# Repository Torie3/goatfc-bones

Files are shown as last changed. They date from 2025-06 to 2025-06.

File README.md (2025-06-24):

# 🐐 GoatFC-Bones - Open Source FPV Flight Controller

<div align="left">
  <p>
    <strong>GoatFC-Bones</strong> is a compact, cheap, open-source FPV drone flight controller designed for racing builds without sacrificing performance. It’s ideal for hobbyists who want simple hardware so that they can easily understand what is happening in their quadcopter.
  </p>
</div>

GoatFC-Bones Flight Controller

## 🔧 Key Features

- **Voltage Regulation:**
  - 5V and 12V BEC outputs
  - Dual 3.3V LDOs:
    - One dedicated to the IMU for **noise isolation**
    - One for the rest of the system

- **Connectivity:**
  - Micro-USB for configuration
  - 20x20mm standard mounting pattern
  - ESC connector for clean wiring
  - 6-pin HD video system plug

- **Software:**
  - Compatible with [Betaflight](https://betaflight.com/) no official target yet!

- **License & Use:**
  - **Open-source** – build it, modify it, improve it
  - **Non-commercial** – redistribution for sale is **not allowed**
## 🧷 Pinout Diagram

Below is the pinout for the GoatFC-Bones flight controller. Make sure to reference this schematic when wiring your components.

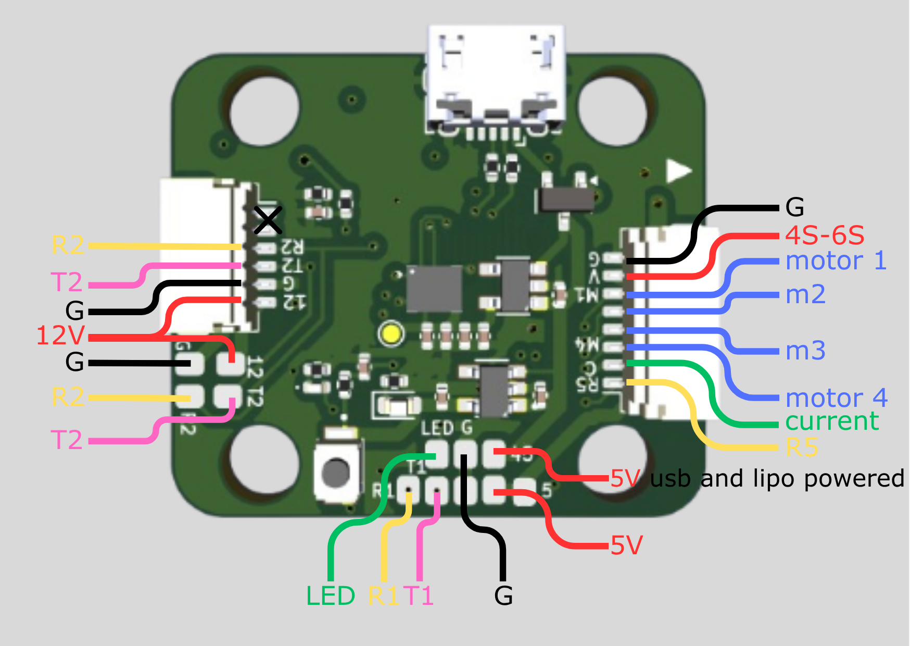
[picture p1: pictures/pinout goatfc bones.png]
GoatFC-Bones Pinout


> ⚠️ **Note:** The dedicated 3.3V regulators *are* broken out on the board, but **they are not intended for external use**. If you're curious about their exact location or implementation, please refer to the KiCad design files. Avoid connecting anything to these lines unless you fully understand the design — using them improperly may cause instability or damage.

> 🔌 Always double-check with a multimeter before connecting components!
## 🛠️ Building Your Own GoatFC-Bones

Amazing that you want to build one!

You can order the PCBs from your favorite PCB manufacturer — the Gerber files are available in the folder:  
[Gerber Files Folder](./gerber%20files)

### 📦 Bill of Materials (BOM)

The BOM is provided as an **interactive BOM**, which you can view here:  
[Download and open html file here](./interactive-bom)

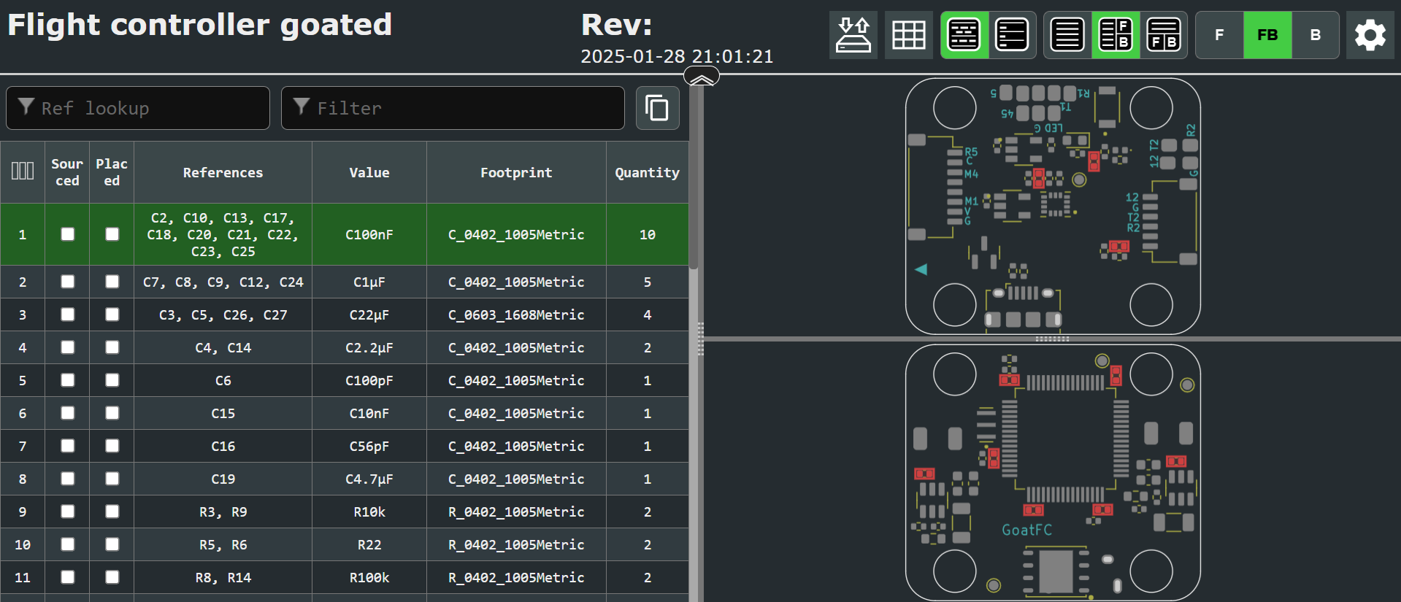
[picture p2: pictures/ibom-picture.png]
IBOM showcase


The iBOM makes it easy to locate and identify all the required components. Just search for the parts and order them from your preferred distributor.

### 🔧 Assembly Tips

- Solder all components following the iBOM placement guide
- Use **solder paste** and a **hot air station** for best results
- All components are **0402 size** — small, but manageable with some patience
- If you're new to SMD soldering, it's a good idea to practice on a scrap board first!

Good luck, and enjoy flying with your custom GoatFC-Bones FC!

## Flashing Betaflight to GoatFC-Bones

Follow these steps to flash Betaflight firmware to your GoatFC-Bones flight controller:

### Requirements
- A fully assembled GoatFC-Bones FC
- [Betaflight Configurator](https://github.com/betaflight/betaflight-configurator/releases) (latest version) installed on your PC

### Flashing Steps

1. **Build and assemble** your GoatFC-Bones FC.
2. **Install the latest Betaflight Configurator** on your computer.
3. **Enter DFU mode**:
   - Hold down the **boot button** on the FC while plugging in the **Micro-USB** cable.
4. In Betaflight Configurator, your FC should now show up as **DFU Bootloader**.
5. Go to the **Firmware Flasher** tab.
6. Under **Board**, select:  
   **`FOXEERF722V4`** (GoatFC-Bones shares a pinout with the Foxeer Mini V4).
7. Choose your preferred **firmware version** from the dropdown.
8. Click **Load Firmware [Online]**.
9. Then click **Flash Firmware**.
10. Once flashing is complete, the firmware is installed and ready to go! 🎉

### ⚠️ Important: Motor Remapping Required

Because the motor layout on GoatFC-Bones differs from the Foxeer Mini V4, you must **remap the motors** in the CLI:

1. Go to the **CLI** tab
2. In the cli type:
```
resource MOTOR 1 PC08
resource MOTOR 2 PC09
resource MOTOR 3 PA08
resource MOTOR 4 PA09
save
```
4. Now your motors should be in the correct order.
- You only need to do this once — after that, you can **save your configuration as a preset** to reload easily next time.

> 💡 Tip: After remapping, test motor directions in the “Motors” tab and double-check the order before your first flight.

---

## ⚠️ Disclaimer

This project is provided **as-is** without any warranty or guarantee of functionality or safety.

By using the GoatFC-Bones design files, firmware configurations, or build instructions, you acknowledge and agree that:

- You are solely responsible for your own safety and the safety of others.
- You assume all risks associated with the assembly, flashing, and use of this hardware.
- I (the creator) am **not liable** for any damage, injury, loss, or malfunction resulting from the use, misuse, or failure of this project.
- Always follow proper electrical and flight safety practices, and ensure compliance with your local laws and regulations.

> 🚧 Use at your own risk. This is an open-source DIY project intended for educational and recreational purposes (drone racing an amazing hobby!).

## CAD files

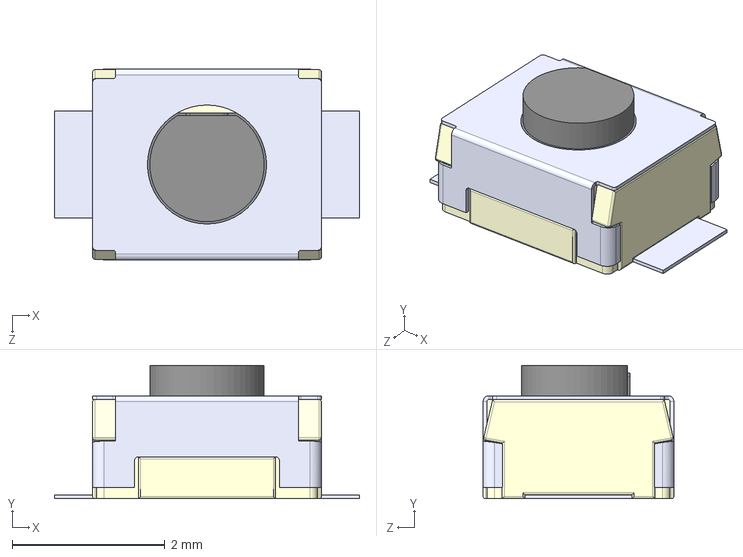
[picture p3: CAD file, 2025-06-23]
custom symbols and footprints/button/boot button/B3U-1000P/B3U-1000P.step
4.00 x 1.75 x 2.50 mm

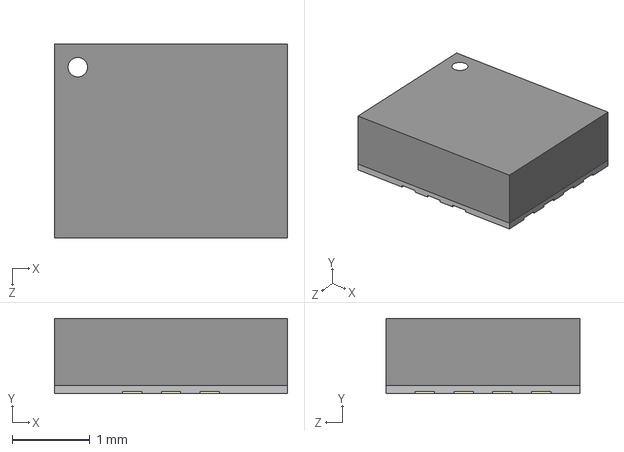
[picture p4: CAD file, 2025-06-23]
custom symbols and footprints/Chips/gyro/ICM-42688-P/ICM-42688-P.step
3.00 x 0.97 x 2.50 mm

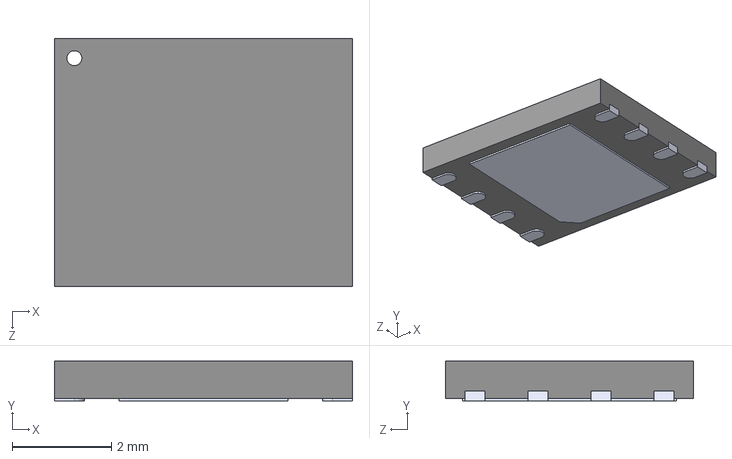
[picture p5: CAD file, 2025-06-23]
custom symbols and footprints/Chips/memory/W25Q128JVPIQ/W25Q128JVPIQ.step
6.00 x 0.8 x 5.00 mm

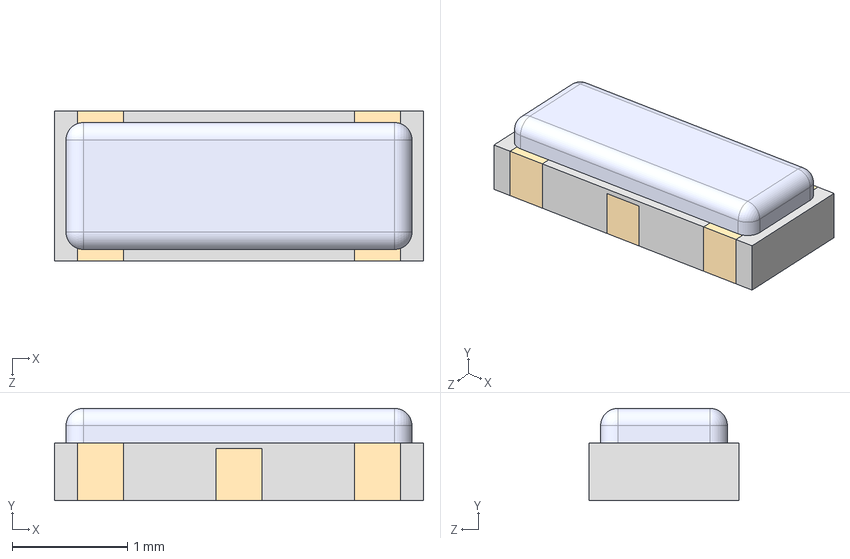
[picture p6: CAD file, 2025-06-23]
custom symbols and footprints/Chips/oscillator/CSTNE8M00G550000R0/CSTNE8M00G550000R0.step
3.20 x 0.8 x 1.30 mm

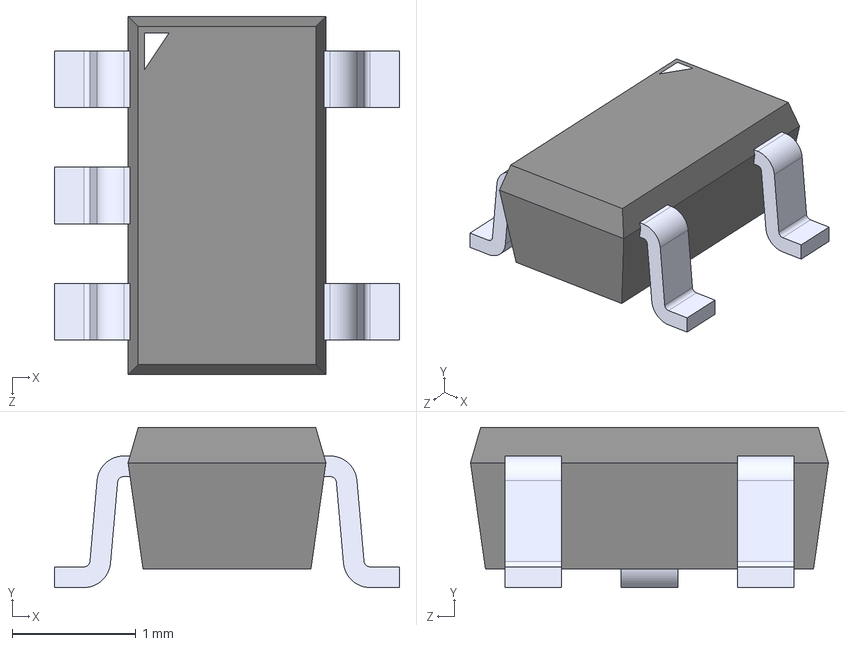
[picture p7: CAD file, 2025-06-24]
custom symbols and footprints/Chips/voltage regulator/RT9013-33GB/RT9013-33GB.step
2.79 x 1.30 x 2.90 mm

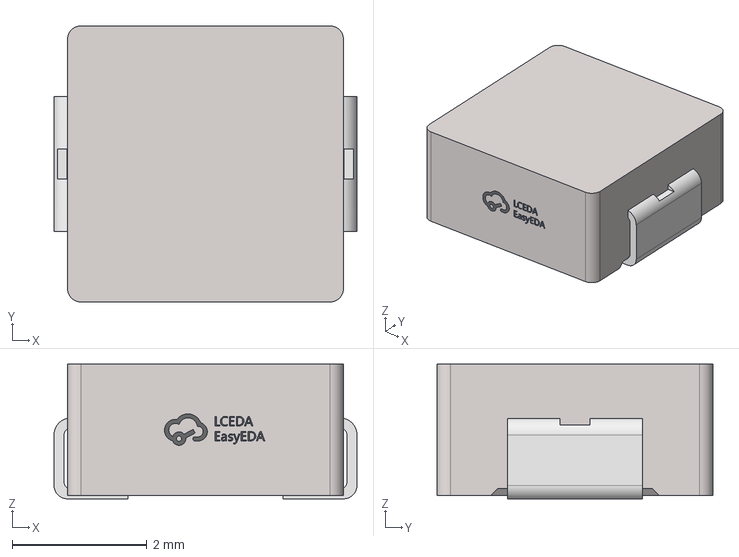
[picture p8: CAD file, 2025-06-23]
custom symbols and footprints/coils/TECHFUSE SL0420-100M.stp
4.50 x 4.10 x 2.00 mm

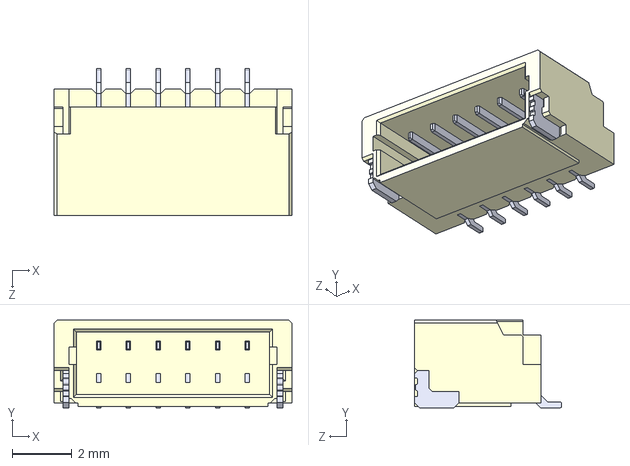
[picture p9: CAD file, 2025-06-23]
custom symbols and footprints/Connectors/jst-sh1.0/SM06B-SRSS-TB_LF__SN_/SM06B-SRSS-TB_LF__SN_.step
8.00 x 2.95 x 4.95 mm

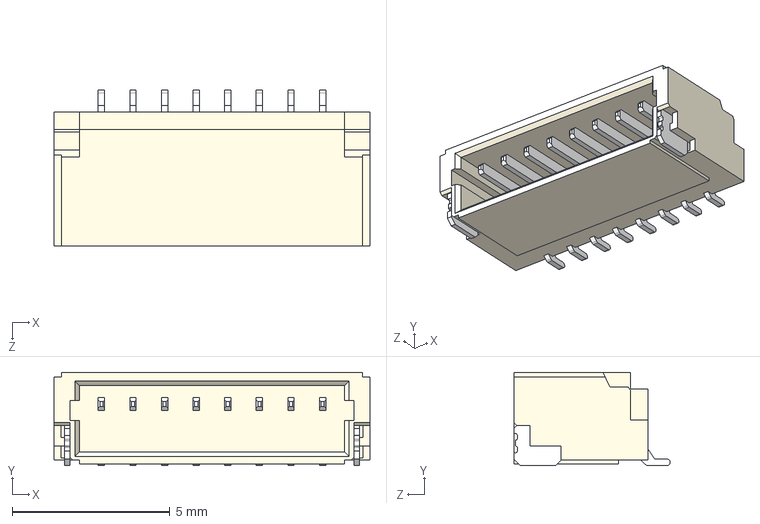
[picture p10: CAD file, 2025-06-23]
custom symbols and footprints/Connectors/jst-sh1.0/SM08B-SRSS-TB_LF__SN_/SM08B-SRSS-TB_LF__SN_.step
10.00 x 2.95 x 4.95 mm

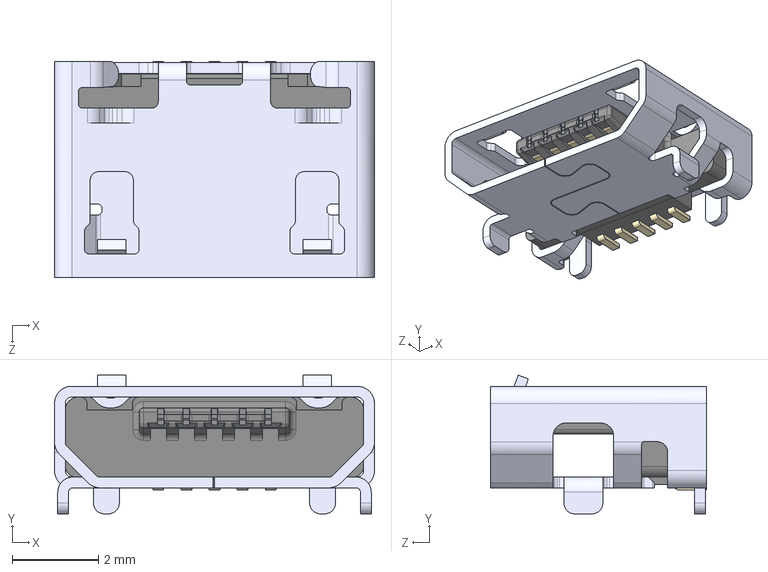
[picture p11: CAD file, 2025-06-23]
custom symbols and footprints/Connectors/usb/10118194-0011LF/10118194-0011LF.step
7.40 x 3.21 x 5.00 mm

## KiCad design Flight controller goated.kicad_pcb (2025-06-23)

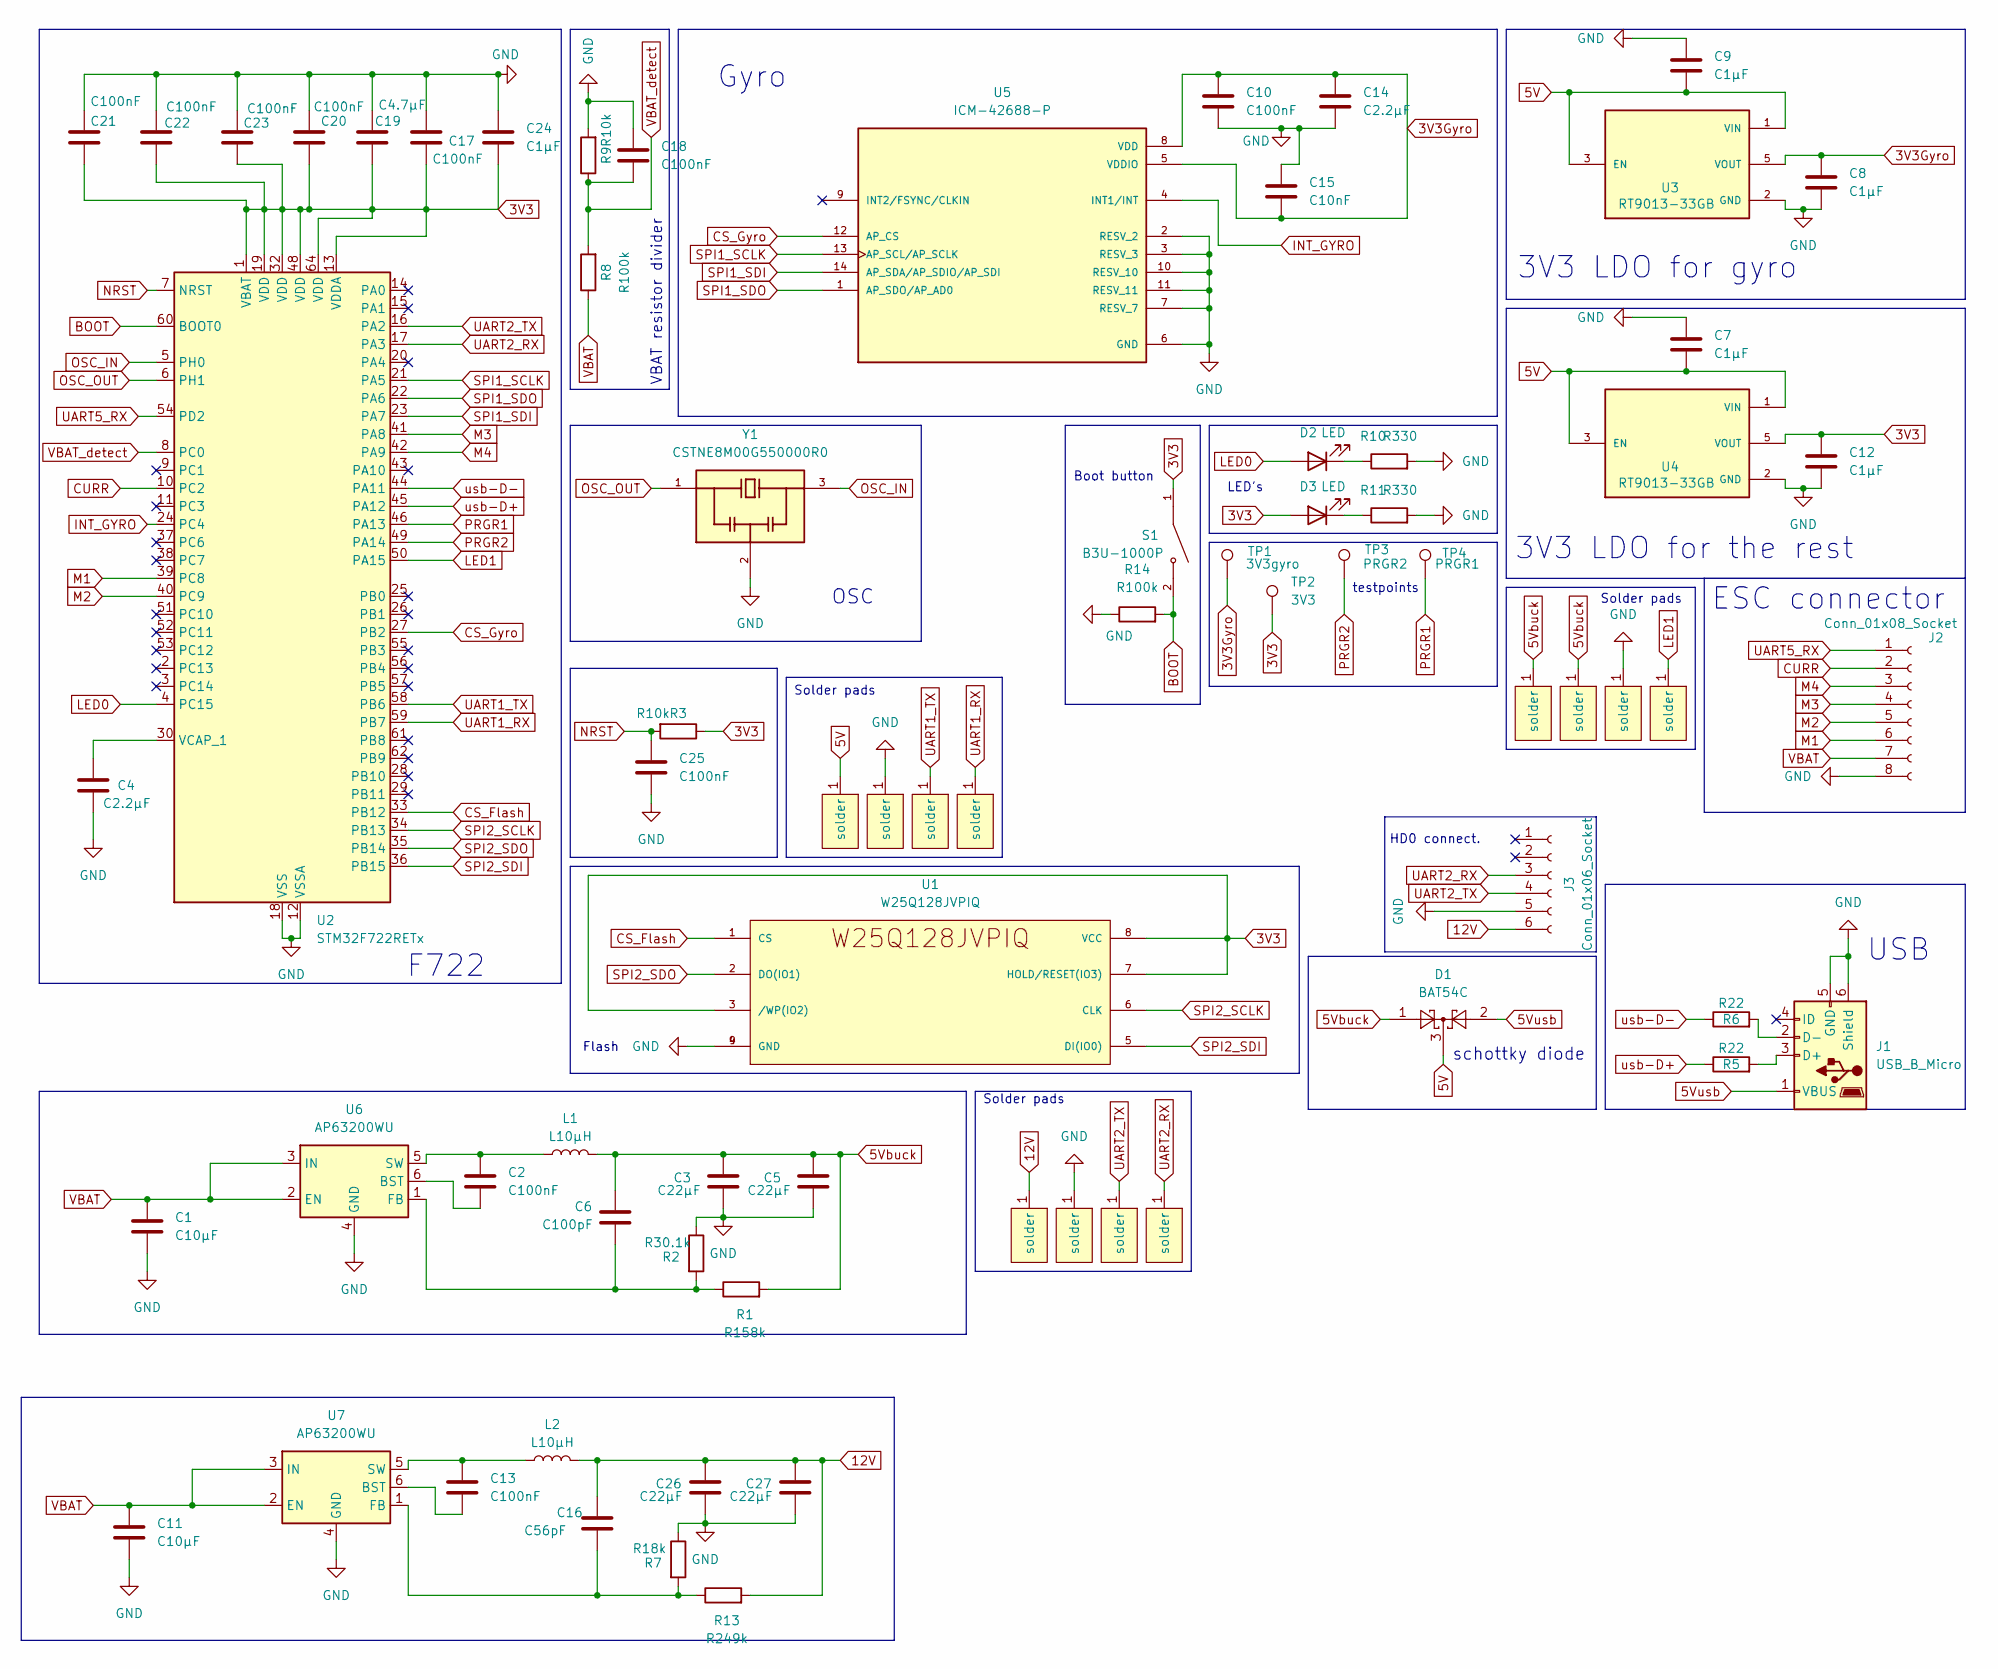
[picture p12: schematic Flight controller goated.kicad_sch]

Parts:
C1, C11: C10µF; C_1206_3216Metric
C2, C10, C13, C17, C18, C20, C21, C22, C23, C25: C100nF; C_0402_1005Metric
C3, C5, C26, C27: C22µF; C_0603_1608Metric
C4, C14: C2.2µF; C_0402_1005Metric
C6: C100pF; C_0402_1005Metric
C7, C8, C9, C12, C24: C1µF; C_0402_1005Metric
C15: C10nF; C_0402_1005Metric
C16: C56pF; C_0402_1005Metric
C19: C4.7µF; C_0402_1005Metric
D1: BAT54C; SOT-23
D2: LED; LED_0402_1005Metric
D3: LED; LED_0603_1608Metric
J1: USB_B_Micro; USB_Micro-B_Amphenol_10118194-0001LF_Horizontal
J2: Conn_01x08_Socket; JST_SH_SM08B-SRSS-TB_1x08-1MP_P1.00mm_Horizontal
J3: Conn_01x06_Socket; JST_SH_SM06B-SRSS-TB_1x06-1MP_P1.00mm_Horizontal
L1, L2: L10µH; TECHFUSE SL0420-100M
R1: R158k; R_0603_1608Metric
R2: R30.1k; R_0402_1005Metric
R3, R9: R10k; R_0402_1005Metric
R5, R6: R22; R_0402_1005Metric
R7: R18k; R_0402_1005Metric
R8, R14: R100k; R_0402_1005Metric
R10, R11: R330; R_0402_1005Metric
R13: R249k; R_0603_1608Metric
S1: B3U-1000P; SW_B3U-1000P
S2, S3, S4, S5, S6, S7, S8, S9, S10, S11, S12, S13: solder pad; solder pad small
TP1: 3V3gyro; TestPoint_Pad_D1.0mm
TP2: 3V3; TestPoint_Pad_D1.0mm
TP3: PRGR2; TestPoint_Pad_D1.0mm
TP4: PRGR1; TestPoint_Pad_D1.0mm
U1: W25Q128JVPIQ
U2: STM32F722RETx; LQFP-64_10x10mm_P0.5mm
U3, U4: RT9013-33GB; SOT94P279X129-5N; PARTREV Aprill 2011
U5: ICM-42688-P; PQFN50P300X250X97-14N; PARTREV 1.2
U6, U7: AP63200WU; TSOT-23-6
Y1: CSTNE8M00G550000R0; OSC_CSTNE8M00G550000R0

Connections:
3V3: C12.1, C17.2, C19.2, C20.2, C21.2, C22.2, C23.2, C24.2, D3.2 (A), R3.1, S1.1, TP2.1, U1.3 (/WP(IO2)), U1.7 (HOLD/RESET(IO3)), U1.8 (VCC), U2.1 (VBAT), U2.13 (VDDA), U2.19 (VDD), U2.32 (VDD), U2.48 (VDD), U2.64 (VDD), U4.5 (VOUT)
3V3Gyro: C8.1, C10.1, C14.1, C15.2, TP1.1, U3.5 (VOUT), U5.5 (VDDIO), U5.8 (VDD)
5V: C7.2, C9.2, D1.3, S6.1 (solder), U3.1 (VIN), U3.3 (EN), U4.1 (VIN), U4.3 (EN)
5Vbuck: C3.1, C5.1, C6.2, D1.1, L1.2, R1.2, S10.1 (solder), S13.1 (solder)
5Vusb: D1.2, J1.1 (VBUS)
12V: C16.2, C26.1, C27.1, J3.6, L2.2, R13.2, S2.1 (solder)
BOOT: R14.2, S1.2, U2.60 (BOOT0)
CS_Flash: U1.1 (CS), U2.33 (PB12)
CS_Gyro: U2.27 (PB2), U5.12 (AP_CS)
CURR: J2.2, U2.10 (PC2)
GND: C1.2, C3.2, C4.2, C5.2, C7.1, C8.2, C9.1, C10.2, C11.2, C12.2, C14.2, C15.1, C17.1, C18.1, C19.1, C20.1, C21.1, C22.1, C23.1, C24.1, C25.2, C26.2, C27.2, J1.5 (GND), J1.6 (Shield), J2.8, J3.5, R2.1, R7.1, R9.2, R10.2, R11.2, R14.1, S3.1 (solder), S7.1 (solder), S11.1 (solder), U1.4 (GND), U1.9 (GND), U2.12 (VSSA), U2.18 (VSS), U2.31 (VSS), U2.47 (VSS), U2.63 (VSS), U3.2 (GND), U4.2 (GND), U5.2 (RESV_2), U5.3 (RESV_3), U5.6 (GND), U5.7 (RESV_7), U5.10 (RESV_10), U5.11 (RESV_11), U6.4 (GND), U7.4 (GND), Y1.2
INT_GYRO: U2.24 (PC4), U5.4 (INT1/INT)
LED0: D2.2 (A), U2.4 (PC15)
LED1: S12.1 (solder), U2.50 (PA15)
M1: J2.6, U2.39 (PC8)
M2: J2.5, U2.40 (PC9)
M3: J2.4, U2.41 (PA8)
M4: J2.3, U2.42 (PA9)
NRST: C25.1, R3.2, U2.7 (NRST)
unnamed: D2.1 (K), R10.1
unnamed: D3.1 (K), R11.1
unnamed: J1.3 (D+), R5.2
unnamed: J1.2 (D-), R6.2
unnamed: C4.1, U2.30 (VCAP_1)
unnamed: C2.2, U6.6 (BST)
unnamed: C6.1, R1.1, R2.2, U6.1 (FB)
unnamed: C2.1, L1.1, U6.5 (SW)
unnamed: C13.2, U7.6 (BST)
unnamed: C16.1, R7.2, R13.1, U7.1 (FB)
unnamed: C13.1, L2.1, U7.5 (SW)
OSC_IN: U2.5 (PH0), Y1.3
OSC_OUT: U2.6 (PH1), Y1.1
PRGR1: TP4.1, U2.46 (PA13)
PRGR2: TP3.1, U2.49 (PA14)
SPI1_SCLK: U2.21 (PA5), U5.13 (AP_SCL/AP_SCLK)
SPI1_SDI: U2.23 (PA7), U5.14 (AP_SDA/AP_SDIO/AP_SDI)
SPI1_SDO: U2.22 (PA6), U5.1 (AP_SDO/AP_AD0)
SPI2_SCLK: U1.6 (CLK), U2.34 (PB13)
SPI2_SDI: U1.5 (DI(IO0)), U2.36 (PB15)
SPI2_SDO: U1.2 (DO(IO1)), U2.35 (PB14)
UART1_RX: S9.1 (solder), U2.59 (PB7)
UART1_TX: S8.1 (solder), U2.58 (PB6)
UART2_RX: J3.3, S5.1 (solder), U2.17 (PA3)
UART2_TX: J3.4, S4.1 (solder), U2.16 (PA2)
UART5_RX: J2.1, U2.54 (PD2)
VBAT: C1.1, C11.1, J2.7, R8.1, U6.2 (EN), U6.3 (IN), U7.2 (EN), U7.3 (IN)
VBAT_detect: C18.2, R8.2, R9.1, U2.8 (PC0)
usb-D+: R5.1, U2.45 (PA12)
usb-D-: R6.1, U2.44 (PA11)

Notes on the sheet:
Solder pads
F722
schottky diode
Gyro
3V3 LDO for the rest
VBAT resistor divider
Boot button
HD0 connect.
USB
testpoints
Flash
OSC
LED's
ESC connector
3V3 LDO for gyro

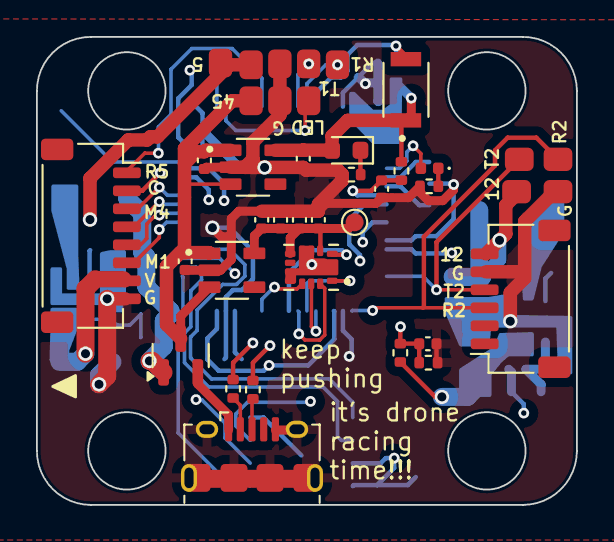
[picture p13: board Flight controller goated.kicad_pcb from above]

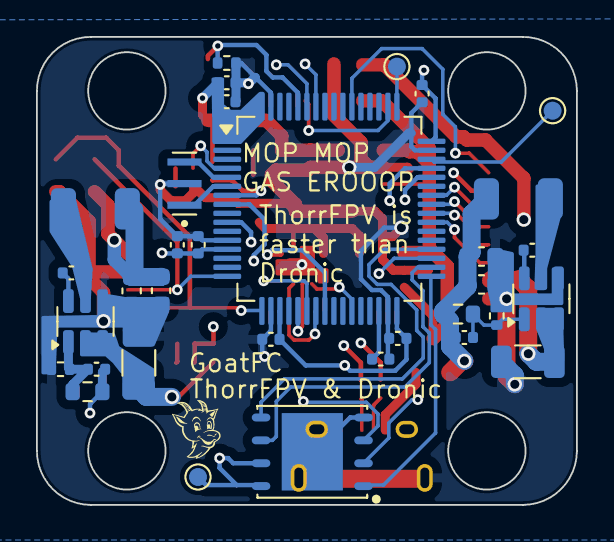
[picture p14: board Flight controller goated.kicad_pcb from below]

Board: 4 copper layers, 30.0 x 26.0 mm, 72 parts (33 on the bottom side), 49 nets.

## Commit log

2025-06-23 add everything lol
    [10118194-0011LF.step, B3U-1000P.step, CSTNE8M00G550000R0.step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]
2025-06-24 added RT9013-33GB reference chip
    [RT9013-33GB.step]
